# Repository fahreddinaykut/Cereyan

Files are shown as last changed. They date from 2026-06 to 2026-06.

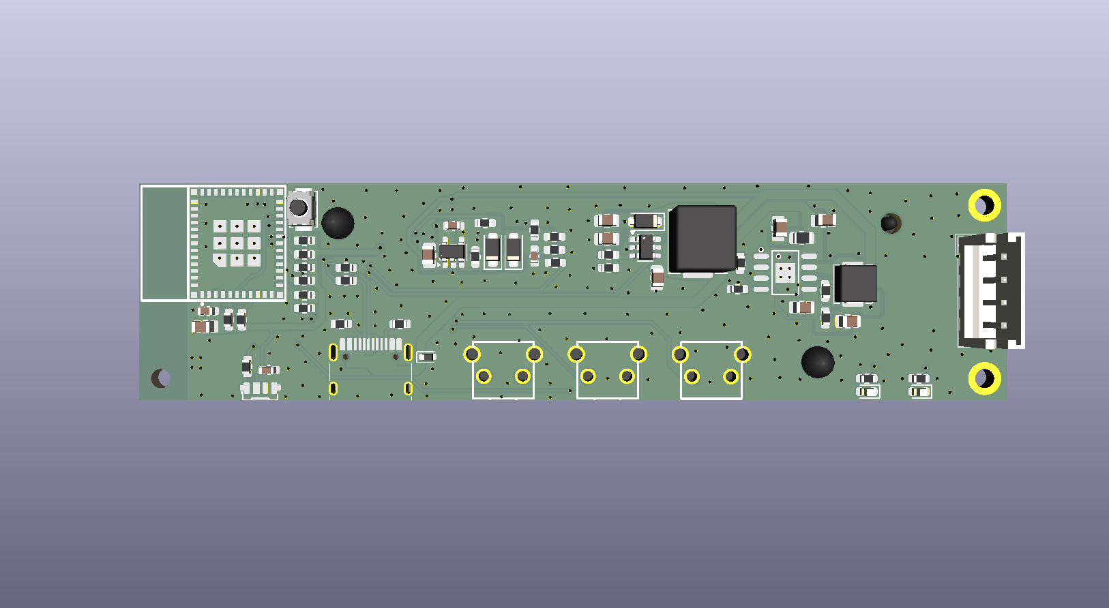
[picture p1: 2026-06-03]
hardware/exports/CereyanV1_render.png

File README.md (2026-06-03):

# Cereyan

Cereyan is a battery-powered smart ventilation fan platform designed for camping and tent airflow control.

The device is intended to attach magnetically to tent windows or fabric-supported openings and provide programmable ventilation through a compact embedded system. Multiple Cereyan units are planned to synchronize over ESP-NOW, allowing coordinated airflow control without requiring Wi-Fi infrastructure.

> Project status: Hardware design completed. PCB fabrication, board bring-up, firmware and mobile application development are planned as next steps.

## Motivation

Ventilation inside tents can be difficult to control, especially during camping, sleeping hours, humid conditions or hot weather. Cereyan is designed as a compact, battery-powered fan controller that can be mounted temporarily and programmed to run automatically.

The long-term goal is to create an open hardware and firmware platform for programmable off-grid ventilation.

## Planned Features

* Battery-powered operation
* USB-C charging input
* ESP32-C3-MINI based control system
* Power latch circuit for low-power wake/start behavior
* Programmable fan speed control
* Scheduled fan operation from a mobile application
* ESP-NOW synchronization between multiple units
* Battery voltage monitoring
* SK6812 addressable status LED
* Magnetic mounting concept for tent window usage

## Hardware Overview

The current hardware design includes:

* ESP32-C3-MINI microcontroller
* IP2312 battery charging circuit
* XB7608AJ battery protection IC
* Power latch circuit
* LDO-based system rail control
* MT3608 boost converter
* USB-C input
* SK6812 addressable RGB LED
* Battery voltage sensing
* Fan power/control interface

The power latch circuit allows the device to be started with a physical button. After startup, the ESP32-C3 takes control of the LDO enable pin to keep the system powered. This allows the firmware to manage shutdown behavior and reduce unnecessary battery drain.

## System Concept

A typical use case:

1. The user attaches one or more Cereyan fan units to tent windows using magnets.
2. Each unit powers up from its internal battery.
3. Units communicate with each other using ESP-NOW.
4. A mobile application is used to configure fan schedules and speed profiles.
5. The system automatically turns fans on/off or adjusts speed based on the programmed schedule.

Example planned commands:

* Turn fan on at a specific time
* Turn fan off at a specific time
* Set fan speed
* Read battery voltage
* Synchronize multiple units
* Apply the same schedule to a group of devices

## Current Status

Completed:

* PCB design
* Main hardware architecture
* Power latch concept
* Battery charging/protection section
* ESP32-C3 control section
* USB-C input section
* Boost converter section
* Status LED section

Pending:

* PCB manufacturing
* Board bring-up
* Electrical validation
* Firmware implementation
* ESP-NOW protocol design
* Mobile application
* Mechanical mounting validation
* Real-world camping tests

## Repository Structure

```text
hardware/      KiCad project files, schematic, PCB layout, BOM and manufacturing outputs
firmware/      ESP32-C3 firmware source code
mobile-app/    Mobile application source code
docs/          Design notes, bring-up checklist and roadmap
images/        Project images, renders and diagrams
```

## Roadmap

### Hardware Bring-up

* Verify power rails
* Test USB-C charging
* Validate battery protection behavior
* Test power latch operation
* Verify ESP32-C3 boot and programming
* Test battery voltage measurement
* Test fan output stage
* Test SK6812 LED

### Firmware

* Basic board support package
* Power management logic
* Fan speed control
* Battery voltage measurement
* LED status indication
* ESP-NOW communication
* Schedule execution logic
* Configuration storage

### Mobile Application

* Device discovery
* Fan speed control
* Schedule configuration
* Battery status display
* Multi-device grouping
* ESP-NOW gateway/configuration workflow

## Design Goals

* Practical off-grid usage
* Low standby power
* Simple charging through USB-C
* Field-programmable operation
* Multi-device synchronization
* Open and reproducible design
* Clear documentation for makers and embedded developers

## License

Hardware and software licensing will be finalized as the project progresses.

Suggested options:

* Hardware: CERN-OHL-S or CERN-OHL-P
* Firmware and mobile software: MIT License or Apache-2.0

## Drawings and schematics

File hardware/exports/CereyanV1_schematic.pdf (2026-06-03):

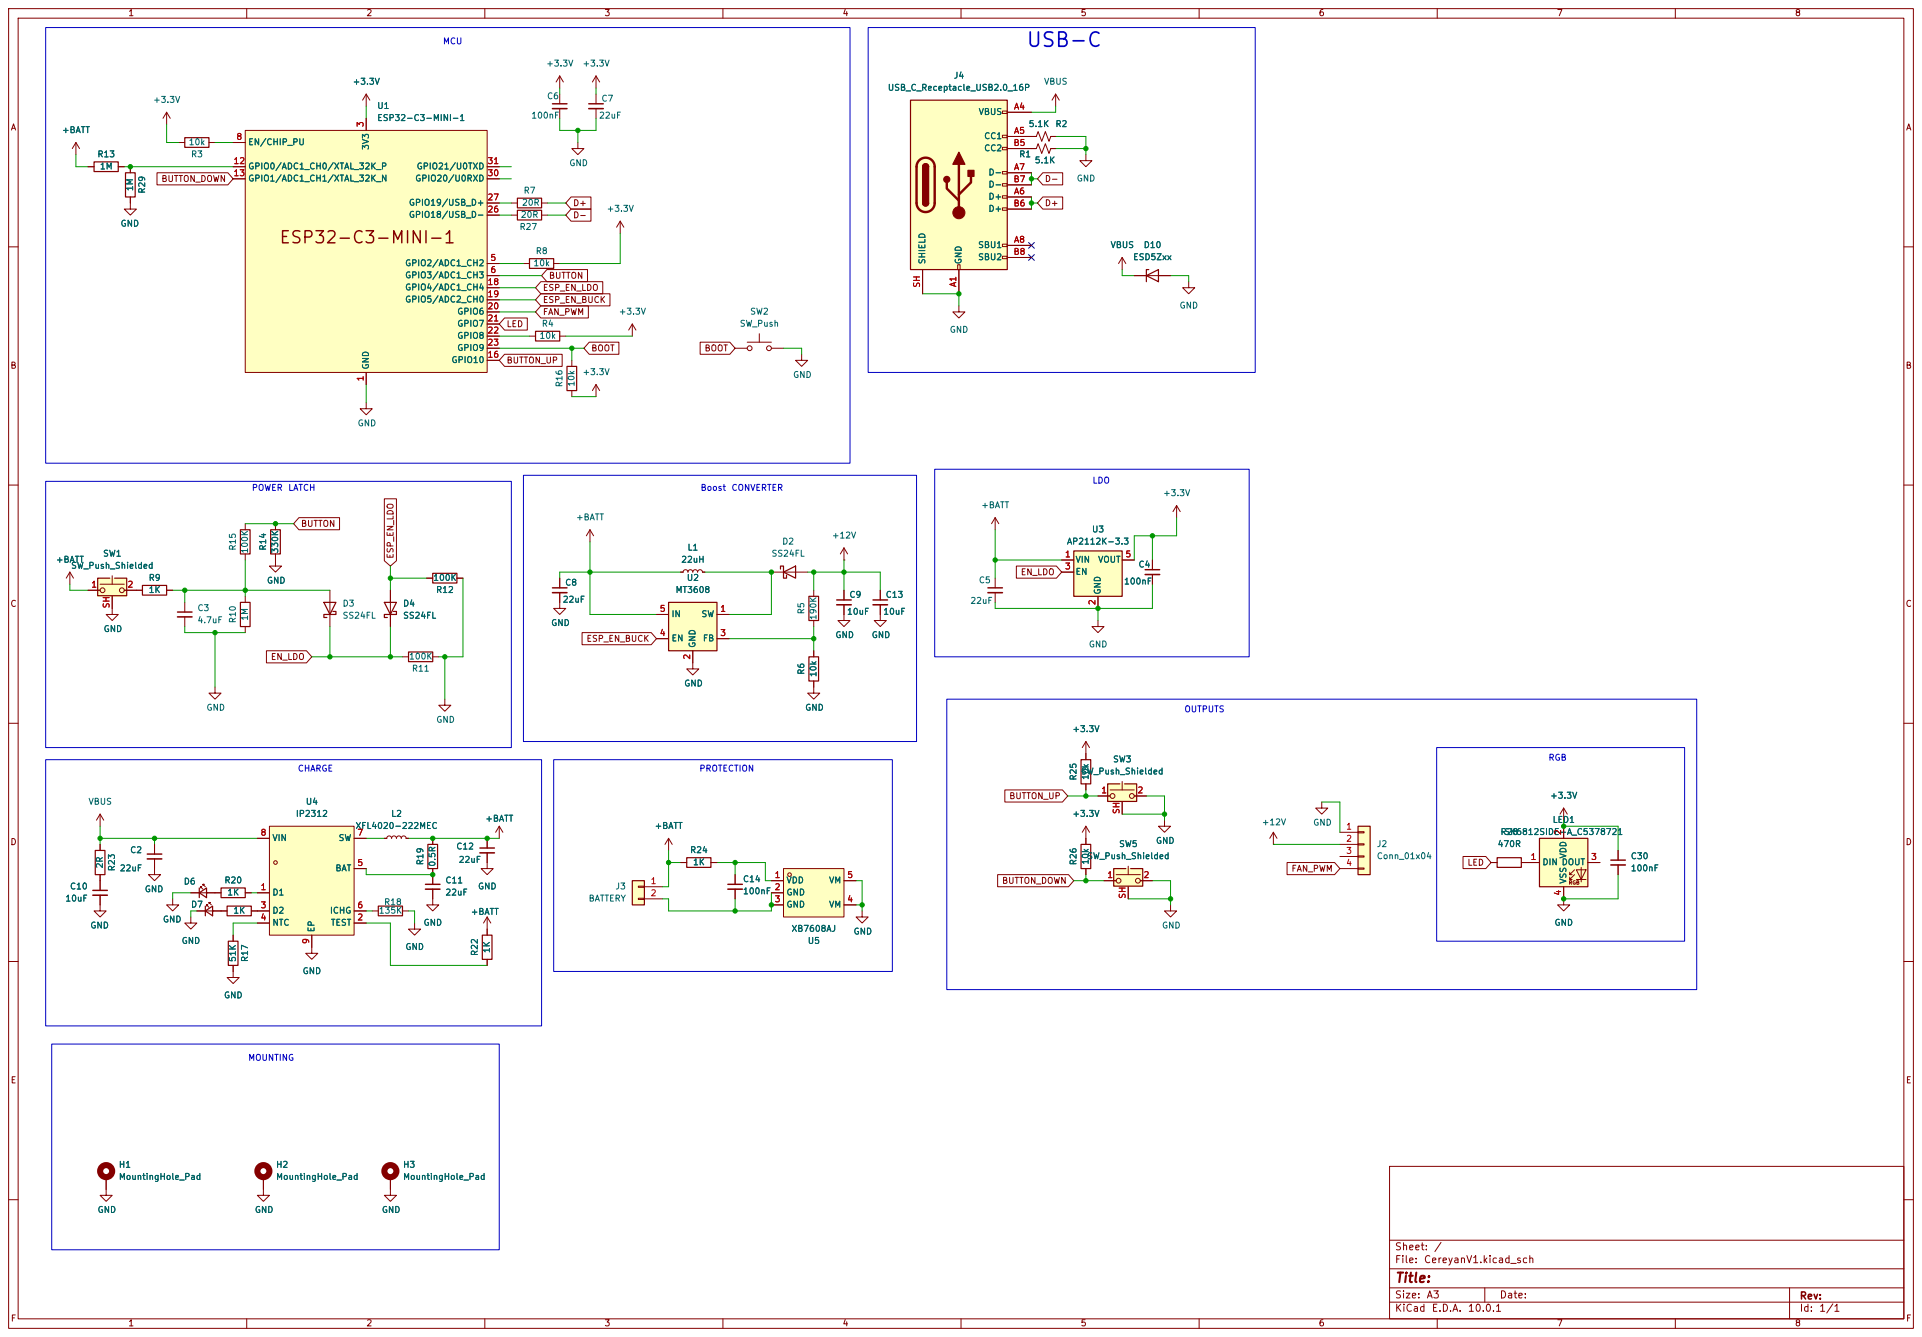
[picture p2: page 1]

9 GND H3MountingHole_Pad GND GND GND H1MountingHole_Pad H2MountingHole_Pad +BATT R22GND 1K
GND

Size: A3 | Rev: | F Date:
KiCad E.D.A. 10.0.1 | Id: 1/1

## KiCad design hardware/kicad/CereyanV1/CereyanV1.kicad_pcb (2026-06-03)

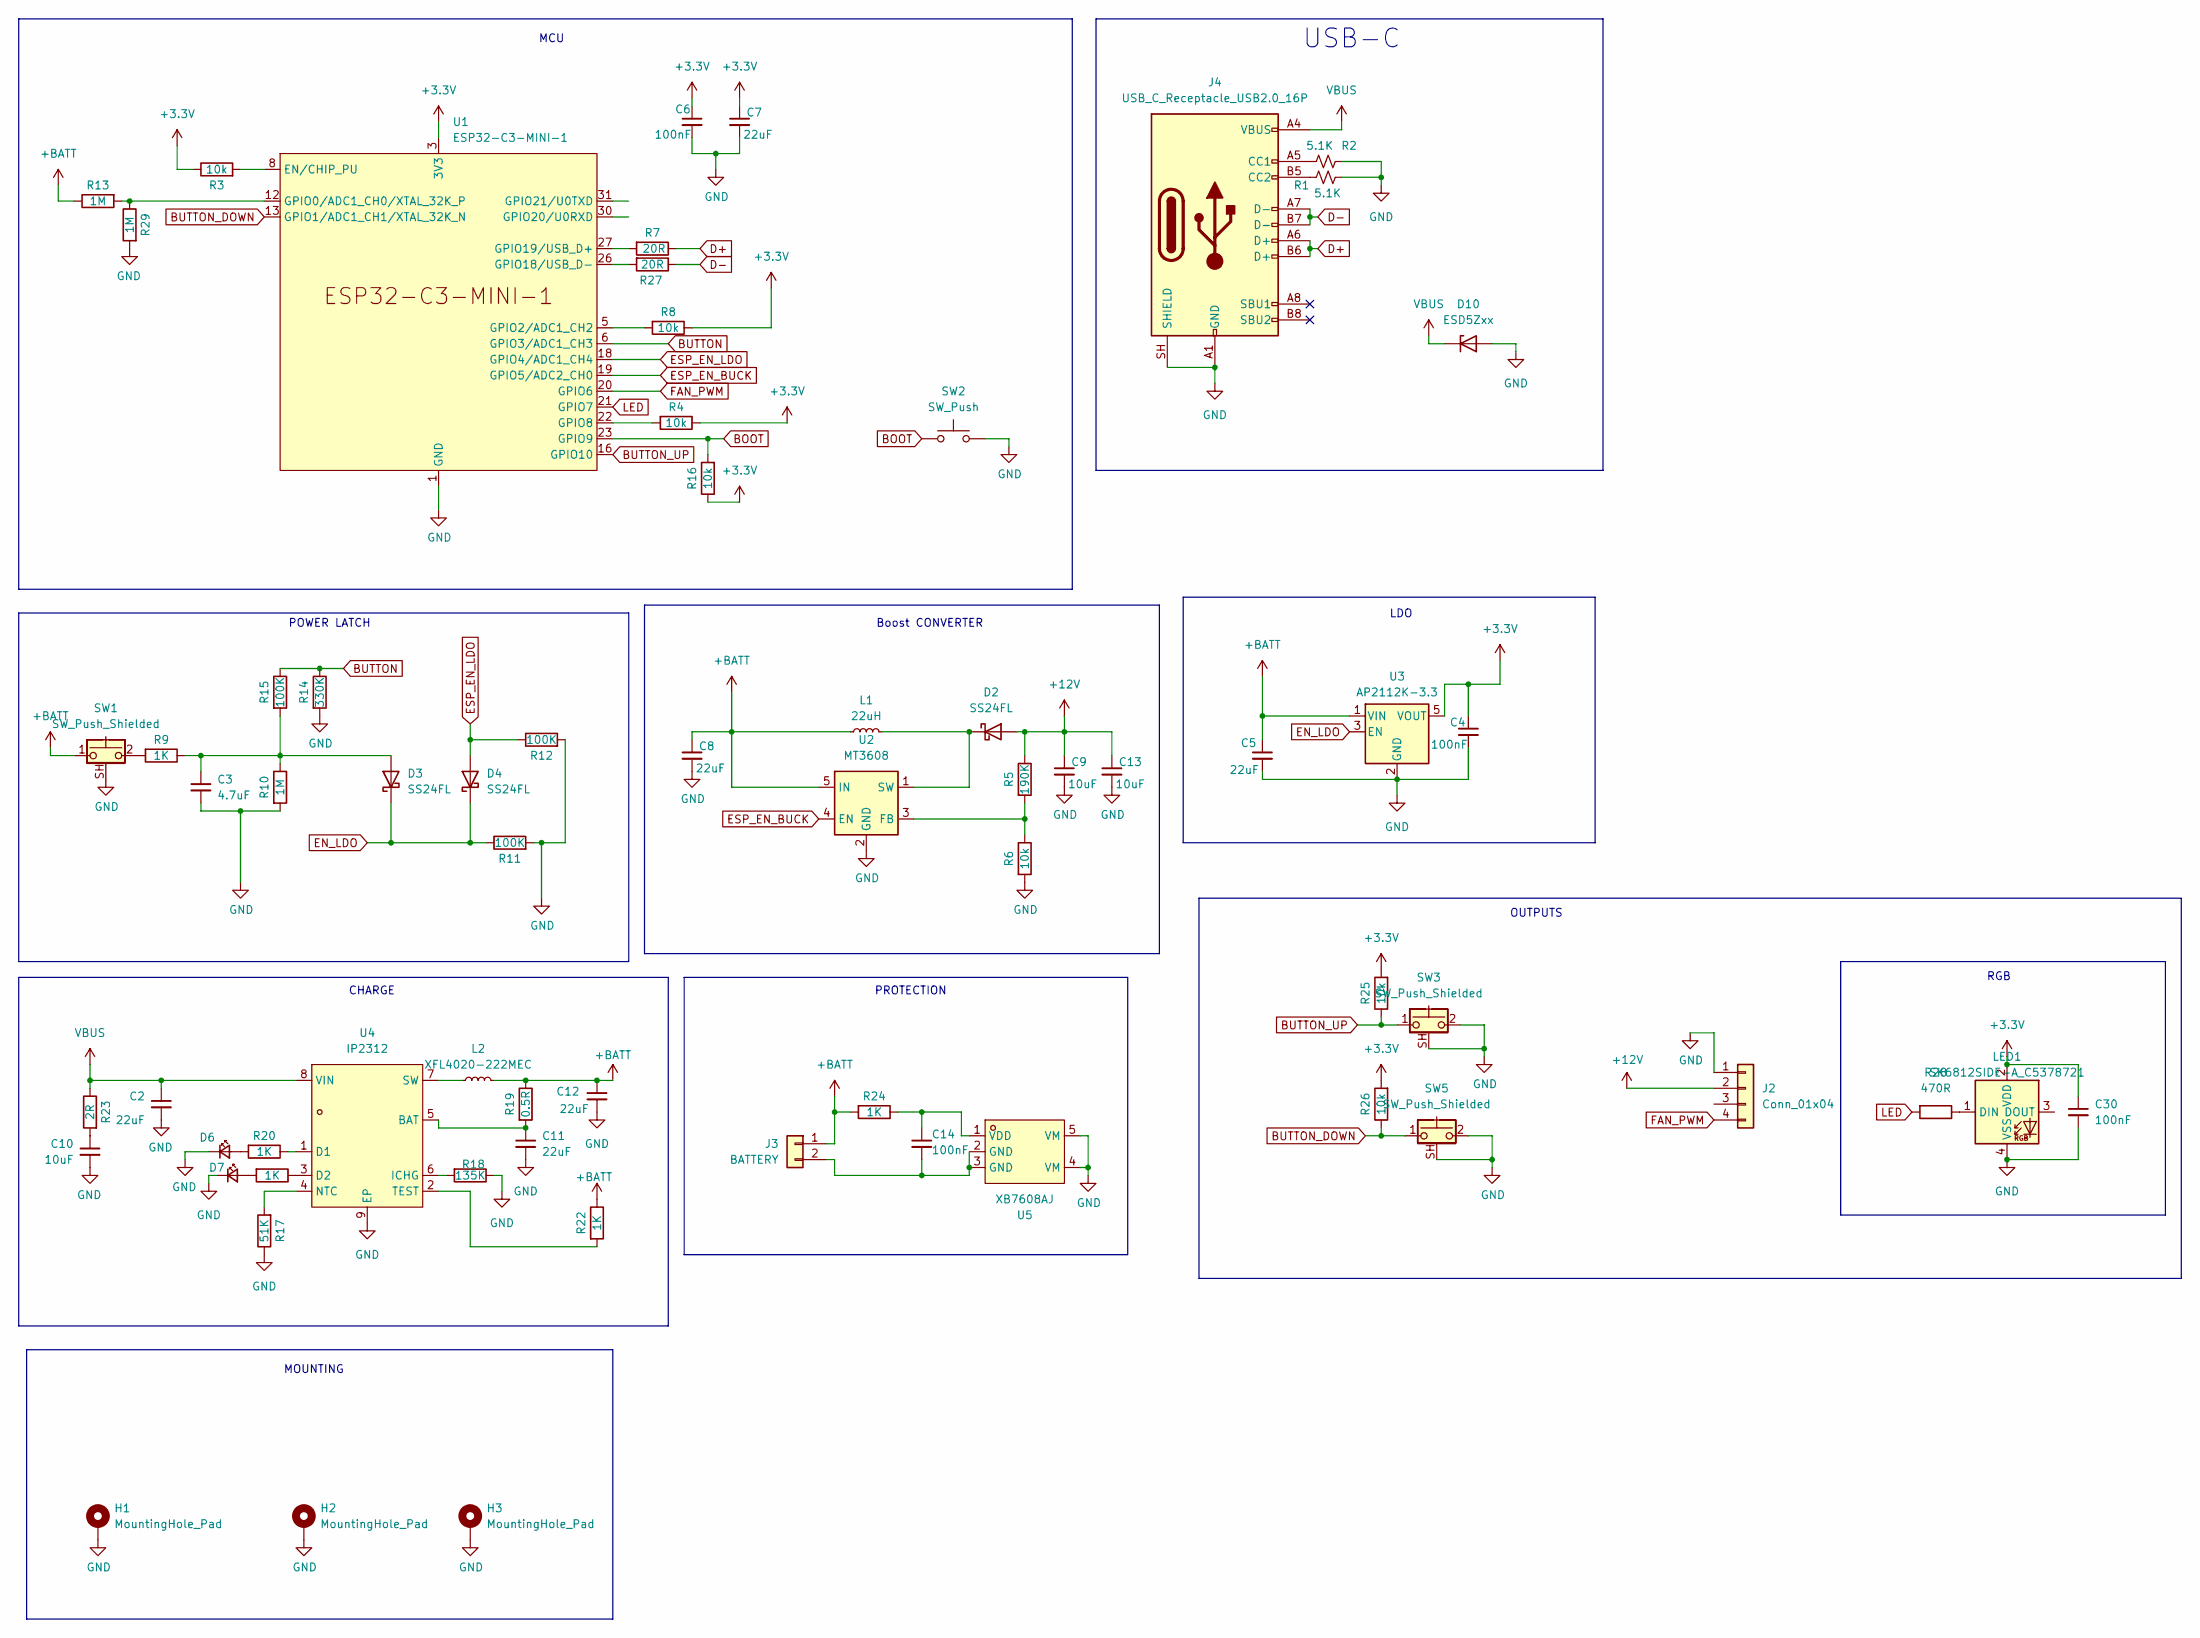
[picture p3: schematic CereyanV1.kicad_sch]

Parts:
C2, C5, C7, C8, C11, C12: 22uF; C_0805_2012Metric
C3: 4.7uF; C_0603_1608Metric
C4, C6, C14: 100nF; C_0603_1608Metric
C9, C10, C13: 10uF; C_0805_2012Metric
C30: 100nF; C_0603_1608Metric; LCSC Part Number C1591
D2, D3, D4: SS24FL; D_SOD-123F
D6, D7: LED_Small; LED_0603_1608Metric
D10: ESD5Zxx; D_SOD-523
H1, H3: MountingHole_Pad; MountingHole_2.2mm_M2_DIN965_Pad
H2: MountingHole_Pad; MountingHole_2.2mm_M2
J2: Conn_01x04; JST_EH_B4B-EH-A_1x04_P2.50mm_Vertical
J3: BATTERY; BatteryHolder_Keystone_1042_1x18650
J4: USB_C_Receptacle_USB2.0_16P; USB_C_Receptacle_HRO_TYPE-C-31-M-12
L1: 22uH; L_TechFuse_SL0650
L2: XFL4020-222MEC; L_APV_APH0420
LED1: SK6812SIDE-A_C5378721; LED-SMD_4P-L4.0-W1.6-L; MPN SK6812SIDE-A; LCSC Part C5378721
R1, R2: 5.1K; R_0603_1608Metric
R3, R4, R6, R8, R16, R25, R26: 10k; R_0603_1608Metric
R5: 190K; R_0603_1608Metric
R7, R27: 20R; R_0603_1608Metric
R9, R20, R21, R22, R24: 1K; R_0603_1608Metric
R10, R13, R29: 1M; R_0603_1608Metric
R11, R12, R15: 100K; R_0603_1608Metric
R14: 330K; R_0603_1608Metric
R17: 51K; R_0603_1608Metric
R18: 135K; R_0603_1608Metric
R19: 0.5R; R_0603_1608Metric
R23: 2R; R_0805_2012Metric
R28: 470R; R_0603_1608Metric; LCSC Part Number C2907044
SW1, SW3, SW5: SW_Push_Shielded; SW-TH_K2-1102AQ-C4CW-01
SW2: SW_Push; SW_Push_SPST_NO_Alps_SKRK
U1: ESP32-C3-MINI-1; WIFIM-SMD_ESP32-C3-MINI-1
U2: MT3608; SOT-23-6
U3: AP2112K-3.3; SOT-23-5
U4: IP2312; SOP-8_L4.9-W3.9-P1.27-LS6.0-BL-EP; MPN IP2312U_VSET; LCSC Part C605432
U5: XB7608AJ; CPC-5_L2.6-W2.6-P0.53-LS4.0-BL; MPN XB7608AJ; LCSC Part C2681921

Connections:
+3.3V: C4.1, C6.1, C7.1, C30.1, LED1.2 (VDD), R3.1, R4.1, R8.1, R16.1, R25.2, R26.2, U1.3 (3V3), U3.5 (VOUT)
+12V: C9.1, C13.1, D2.2 (A), J2.2, R5.1
+BATT: C5.1, C8.1, C12.1, J3.1, L1.1, L2.2, R13.1, R19.1, R22.1, R24.2, SW1.1, U2.5 (IN), U3.1 (VIN)
BOOT: R16.2, SW2.1, U1.23 (GPIO9)
BUTTON: R14.1, R15.1, U1.6 (GPIO3/ADC1_CH3)
BUTTON_DOWN: R26.1, SW5.1, U1.13 (GPIO1/ADC1_CH1/XTAL_32K_N)
BUTTON_UP: R25.1, SW3.1, U1.16 (GPIO10)
D+: J4.A6 (D+), J4.B6 (D+), R7.1
D-: J4.A7 (D-), J4.B7 (D-), R27.1
EN_LDO: D3.1 (K), D4.1 (K), R11.1, U3.3 (EN)
ESP_EN_BUCK: U1.19 (GPIO5/ADC2_CH0), U2.4 (EN)
ESP_EN_LDO: D4.2 (A), R12.1, U1.18 (GPIO4/ADC1_CH4)
FAN_PWM: J2.4, U1.20 (GPIO6)
GND: C2.2, C3.2, C4.2, C5.2, C6.2, C7.2, C8.2, C9.2, C10.2, C11.2, C12.2, C13.2, C30.2, D6.1 (K), D7.1 (K), D10.2 (A), H1.1 (1_1), H2.1, H3.1 (1_1), J2.1, J4.A1 (GND), J4.A12 (GND), J4.B1 (GND), J4.B12 (GND), J4.SH (SHIELD), LED1.4 (VSS), R1.2, R2.2, R6.2, R10.2, R11.2, R12.2, R14.2, R17.1, R18.1, R29.2, SW1.SH (B), SW2.2, SW3.2, SW3.SH (B), SW5.2, SW5.SH (B), U1.1 (GND), U1.2 (GND), U1.11 (GND), U1.14 (GND), U1.36 (GND), U1.37 (GND), U1.38 (GND), U1.39 (GND), U1.40 (GND), U1.41 (GND), U1.42 (GND), U1.43 (GND), U1.44 (GND), U1.45 (GND), U1.46 (GND), U1.47 (GND), U1.48 (GND), U1.49 (GND), U1.50 (GND), U1.51 (GND), U1.52 (GND), U1.53 (GND), U2.2 (GND), U3.2 (GND), U4.9 (EP), U5.4 (VM), U5.5 (VM)
LED: R28.2, U1.21 (GPIO7)
unnamed: C10.1, R23.2
unnamed: D2.1 (K), L1.2, U2.1 (SW)
unnamed: C3.1, D3.2 (A), R9.1, R10.1, R15.2
unnamed: D6.2 (A), R20.2
unnamed: D7.2 (A), R21.2
unnamed: C14.2, J3.2, U5.2 (GND), U5.3 (GND)
unnamed: J4.A5 (CC1), R2.1
unnamed: J4.B5 (CC2), R1.1
unnamed: LED1.1 (DIN), R28.1
unnamed: R9.2, SW1.2
unnamed: R3.2, U1.8 (EN/CHIP_PU)
unnamed: R13.2, R29.1, U1.12 (GPIO0/ADC1_CH0/XTAL_32K_P)
unnamed: R8.2, U1.5 (GPIO2/ADC1_CH2)
unnamed: R4.2, U1.22 (GPIO8)
unnamed: R27.2, U1.26 (GPIO18/USB_D-)
unnamed: R7.2, U1.27 (GPIO19/USB_D+)
unnamed: R5.2, R6.1, U2.3 (FB)
unnamed: C11.1, R19.2, U4.5 (BAT)
unnamed: R20.1, U4.1 (D1)
unnamed: R21.1, U4.3 (D2)
unnamed: R18.2, U4.6 (ICHG)
unnamed: R17.2, U4.4 (NTC)
unnamed: L2.1, U4.7 (SW)
unnamed: R22.2, U4.2 (TEST)
unnamed: C14.1, R24.1, U5.1 (VDD)
VBUS: C2.1, D10.1 (K), J4.A4 (VBUS), J4.A9 (VBUS), J4.B4 (VBUS), J4.B9 (VBUS), R23.1, U4.8 (VIN)

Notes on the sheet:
PROTECTION
POWER LATCH
MCU
USB-C
CHARGE
OUTPUTS
Boost CONVERTER
RGB
LDO
MOUNTING

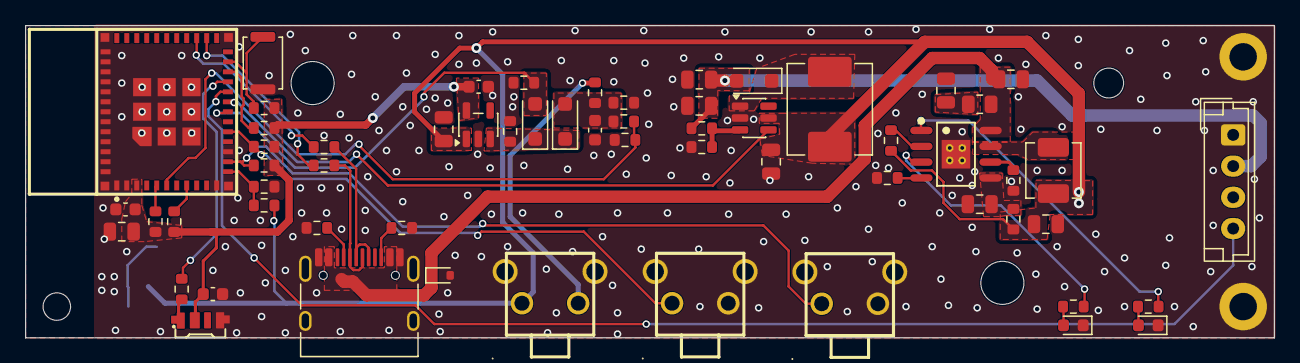
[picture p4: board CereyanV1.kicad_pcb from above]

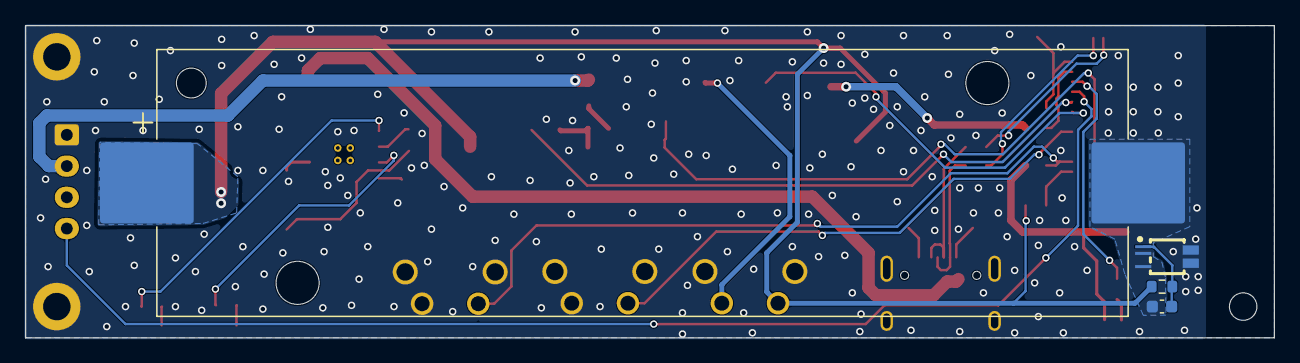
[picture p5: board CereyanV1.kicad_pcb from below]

Board: 2 copper layers, 100.0 x 25.0 mm, 67 parts (4 on the bottom side), 41 nets.
